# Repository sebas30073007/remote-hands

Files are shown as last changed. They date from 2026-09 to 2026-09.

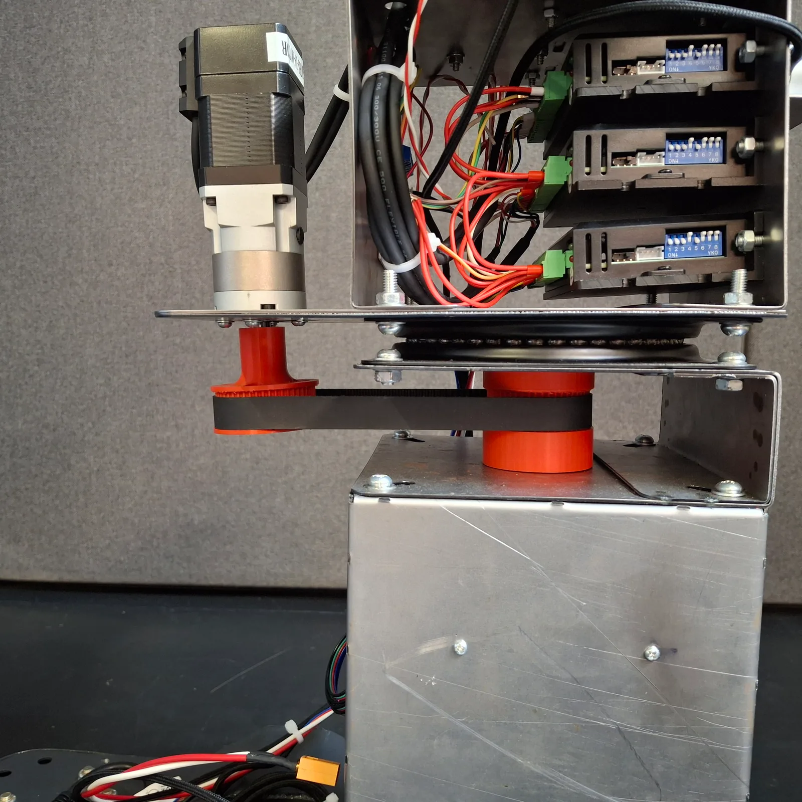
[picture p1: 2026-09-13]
public/images/build/base-rotatoria-lateral.webp

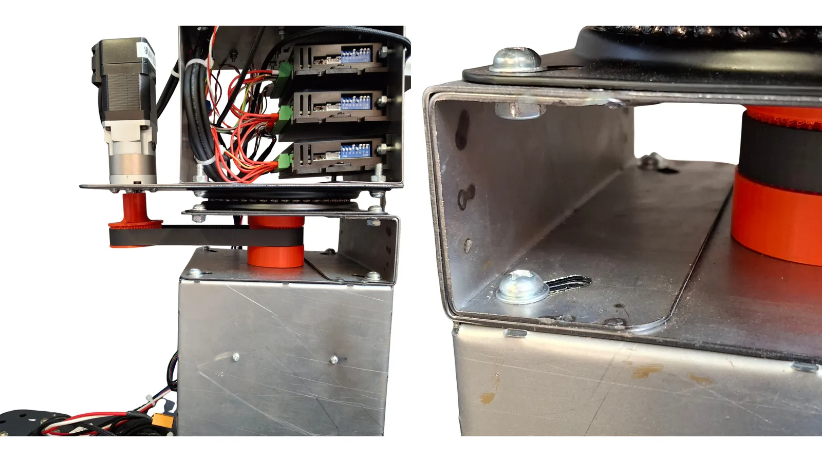
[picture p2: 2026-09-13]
public/images/build/eje-rotacional-base.webp

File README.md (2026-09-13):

# Remote Hands

Documentación de ingeniería de **Remote Hands**: un robot móvil con brazo
manipulador de 3 GDL, teleoperado desde un visor Meta Quest 3.

Un operador controla el robot a distancia con una interfaz de realidad
mixta hecha en Unity. A bordo, una NUC coordina el sistema: procesa la
percepción (RPLiDAR C1 y RealSense D435i), mantiene la comunicación con el
operador por ZeroMQ sobre WiFi y reparte las órdenes entre tres
controladores ESP32-C3 —tracción, manipulador y gripper—.

**Sitio:** [remote-hands.sebs.mx](https://remote-hands.sebs.mx)

Proyecto Terminal universitario. Del experimento de latencia salió un
artículo para el IEEE World Forum on IoT, y el proyecto se postuló al James
Dyson Award 2026.

## Qué hay aquí

Un sitio de documentación construido con [Astro](https://astro.build) y
[Starlight](https://starlight.astro.build). Se escribe en MDX con un
vocabulario de ingeniería propio: requisitos, interfaces, verificación,
decisiones de arquitectura (ADR), niveles de replicación y artefactos
descargables.

Además de la documentación, el repositorio publica lo necesario para
replicar el robot: firmware, código de la NUC, archivos de fabricación de
las PCB, planos DXF del manipulador y el dataset del experimento de latencia.

### Navegación por vista explosionada

El sitio tiene dos formas de navegar, que se alternan con el botón **UI/UX**
de la barra superior:

- **Lista**: el temario clásico.
- **Explosión**: el robot dibujado a partir de su CAD. Al elegir una pieza,
  la página cambia y el dibujo se separa en las piezas de esa parte.

Las imágenes de la explosión no son un modelo 3D embebido: son capas
renderizadas desde el CAD con cámara ortográfica, que el navegador traslada
con CSS.

## Empezar

```bash
npm install
npm run dev       # http://localhost:4321/
npm run build     # genera dist/
npm run check     # tipos y frontmatter
```

## Estructura

```text
src/
├── content/docs/   páginas del sitio (MDX)
├── components/
│   ├── core/       primitivas genéricas
│   └── project/    vocabulario de ingeniería: import { … } from '@project'
├── overrides/      componentes de Starlight sustituidos
├── lib/            configuración del proyecto y árbol de la vista explosionada
├── generated/      manifiesto de la vista explosionada (generado)
└── styles/         identidad SEBS y estilos del sitio
public/
├── models/         modelos 3D optimizados (.glb)
├── explode/        capas renderizadas de la vista explosionada
├── pcb/ firmware/ software/ cad/ datasets/   artefactos descargables
scripts/            pipelines de imágenes y modelos
```

## Pipeline de la vista explosionada

Los modelos originales (Inventor, KiCad) no se versionan: pesan ~50 MB. Si
cambia el CAD, se regeneran así:

```bash
node scripts/optimize-models.mjs   # raw assets/*.glb  ->  public/models/
node scripts/render-explode.mjs    # public/models/    ->  public/explode/ + manifiesto
```

Qué piezas forman cada capa y hacia dónde se separan está en
`scripts/explode-scenes.mjs`; a qué página lleva cada pieza, en
`src/lib/explode-nav.ts`.

## Despliegue

Cada push a `main` compila y publica en GitHub Pages
(`.github/workflows/deploy.yml`). El sitio se sirve en el subdominio
`remote-hands.sebs.mx`, configurado en *Settings → Pages* del repositorio y
con un registro `CNAME` en el DNS de `sebs.mx`.

`site` y `base` están en `astro.config.mjs`. Las rutas internas del
contenido se escriben desde la raíz (`/sistema/…`) y se ajustan al `base` al
compilar, así que mover el sitio a otra ruta solo cambia `BASE`.

## Escribir contenido

El frontmatter `type` (`project`, `subsystem`, `procedure`, `experiment`,
`decision`, `release`, `reference`) coloca la cabecera de la página
automáticamente. Los componentes se importan en una línea:

```mdx
import { ParameterTable, InterfaceTable, Requirement, VerificationResult, Artifact } from '@project';
```

Las páginas de `src/content/docs/sistema/subsistemas/robot-movil/` son la
referencia del patrón.

## Autor

Sebastián Méndez — [sebs.mx](https://sebs.mx)

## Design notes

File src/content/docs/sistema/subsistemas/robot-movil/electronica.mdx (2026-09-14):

---
title: Puente H
description: La placa que mueve los motores DC de tracción — qué es, cómo funciona, cómo se conecta, su PCB y su firmware.
# Tres bloques grandes en el índice de la página: Sinopsis, PCB y Firmware.
tableOfContents:
  minHeadingLevel: 2
  maxHeadingLevel: 2
---

import { ParameterTable, InterfaceTable, Artifact, SignalChain } from '@project';

<figure>
  Módulo Puente H de frente: ESP32-C3, MOSFETs con disipador, capacitor de filtrado y borneras
</figure>

El Puente H es la placa que mueve los motores de tracción del robot. Recibe
una consigna de velocidad y la convierte en la potencia que llega al motor.
El robot lleva dos, uno por motor.

## Sinopsis

### Qué es

Una tarjeta de control de motor DC de **diseño propio**. Usa una topología de
puente H discreto, con aislamiento óptico entre la lógica y la potencia, y un
**ESP32-C3** que gestiona los modos de comunicación.

<ParameterTable
  caption="Características eléctricas"
  rows={[
    { parameter: 'Alimentación de potencia', value: '12–24', unit: 'V DC nominal' },
    { parameter: 'Corriente continua deseada', value: '4–5', unit: 'A' },
    { parameter: 'Corriente pico máxima', value: '8', unit: 'A' },
    { parameter: 'Microcontrolador', value: 'ESP32-C3 SuperMini', unit: '—' },
    { parameter: 'Aislamiento lógica/potencia', value: 'Optoacopladores 4N25', unit: '—' },
    { parameter: 'MOSFETs alto lado', value: 'IRF9540N', unit: 'canal P, 117 mΩ' },
    { parameter: 'MOSFETs bajo lado', value: 'IRF540N', unit: 'canal N, 44 mΩ' },
  ]}
/>

<figure>
  Esquema de bloques funcionales del puente H
  <figcaption>Etapa de potencia, aislamiento óptico, control embebido, expansión I²C y protección.</figcaption>
</figure>

1. **Etapa de potencia** — puente H con MOSFETs IRF540N (N) e IRF9540N (P).
2. **Aislamiento de control** — optoacopladores 4N25 que separan la lógica
   del circuito de conmutación.
3. **Control embebido** — el ESP32-C3 administra modos de comunicación,
   lógica de mando y estados.
4. **Interfaz de expansión** — conectores I²C de entrada y salida para la
   arquitectura maestro-esclavo.
5. **Protección e indicación** — fusible de entrada, capacitor de filtrado,
   LEDs de estado, botón local.

### Cómo funciona

Al encender, la placa lee su DIP switch **una sola vez**, y esa lectura fija
por dónde recibe las órdenes: I²C como maestro o esclavo, WiFi, BLE o
Bluetooth clásico. En el robot, un módulo arranca como maestro y el otro como
esclavo. Por USB-C acepta órdenes siempre, sea cual sea el modo.

#### Modos de operación (DIP switch)

| SW3 | SW2 | SW1 | Modo | Descripción |
| --- | --- | --- | --- | --- |
| 0 | 0 | 0 | Prueba local | Validación interna; rutina activable por botón |
| 0 | 0 | 1 | WiFi | Recibe comandos por red inalámbrica |
| 0 | 1 | 0 | BLE | Bluetooth Low Energy |
| 0 | 1 | 1 | HC-05 | Bluetooth clásico por UART externo |
| 1 | 0 | 0 | I²C Maestro | Nodo maestro en arquitectura distribuida |
| 1 | 0 | 1 | I²C Slave 1 | Esclavo 1 (dirección reservada) |
| 1 | 1 | 0 | I²C Slave 2 | Esclavo 2 (dirección reservada) |
| 1 | 1 | 1 | I²C Slave 3 | Esclavo 3 (dirección reservada) |

La placa arranca con la salida al motor deshabilitada, y solo la habilita
tras una orden explícita de armado. Para mover el motor activa una de las dos
diagonales del puente con PWM: una diagonal gira en un sentido, la otra en el
contrario.

#### Tabla funcional del puente H

`PWM_0 = 1` y `PWM_1 = 1` simultáneamente está **prohibido**: provoca
cortocircuito entre rieles de potencia.

| PWM_0 | PWM_1 | Estado | Descripción |
| --- | --- | --- | --- |
| 0 | 0 | Libre / deshabilitado | Ambos caminos apagados |
| 1 | 0 | Giro A | Activa diagonal A; combinable con PWM |
| 0 | 1 | Giro B | Activa diagonal B; combinable con PWM |
| 1 | 1 | **Prohibido** | Riesgo de cortocircuito |

### Conexiones

De la NUC a las ruedas. El maestro recibe las órdenes por USB y reenvía la
suya al esclavo por I²C; cada módulo mueve su propio motor.

<SignalChain
  porFila={2}
  pasos={[
    { nombre: 'NUC', detalle: 'Python 3.12', imagen: '/images/3d/nuc.webp' },
    { nombre: 'Puente H maestro', detalle: 'ESP32-C3 · DIP 100', imagen: '/images/3d/puente-h.webp' },
    { nombre: 'Puente H esclavo', detalle: 'ESP32-C3 · I²C 0x08', imagen: '/images/3d/puente-h.webp' },
    { nombre: 'Motores DC de tracción', detalle: 'base diferencial · 12–24 V', imagen: '/images/3d/base-diferencial.webp' },
  ]}
  enlaces={['USB-CDC · COM4', 'I²C 0x08 · tramas binarias', 'Salida al motor · uno por módulo']}
/>

<InterfaceTable
  caption="Conectores de la placa"
  columns={['Conector', 'Pines', 'Descripción']}
  rows={[
    ['Entrada de potencia', '2', 'Entrada principal de 12–24 V DC'],
    ['Salida al motor', '2', 'Terminales del puente H hacia la carga'],
    ['Data_in I²C', '4', '+5V, SDA, SCL, GND — recibe el bus desde el maestro'],
    ['Data_out I²C', '4', 'Réplica del bus para encadenar el siguiente módulo'],
    ['Header HC-05', '6', '+5V, GND, RX, TX — Bluetooth clásico o debug UART'],
    ['USB-C (ESP32-C3)', '—', 'Programación, alimentación digital y debug prioritario'],
  ]}
/>

<figure>
  Interior de la caja de elevación con los módulos Puente H montados
  <figcaption>Los dos módulos alojados dentro de la estructura metálica que eleva el manipulador, sobre soportes impresos y sin cajas externas.</figcaption>
</figure>

## PCB

### La placa

Se diseñó en KiCad 9 y se fabricó en JLCPCB. Los valores de abajo están
leídos del archivo de layout, no transcritos: son los que hay que declarar al
pedir la placa.

<ParameterTable
  caption="Especificación de fabricación"
  rows={[
    { parameter: 'Dimensiones', value: '80,6 × 73,4', unit: 'mm' },
    { parameter: 'Capas de cobre', value: '2', unit: 'F.Cu / B.Cu' },
    { parameter: 'Espesor de placa', value: '1,6', unit: 'mm' },
    { parameter: 'Vías', value: '14', unit: '—' },
    { parameter: 'Ancho de pista — potencia', value: '2,0', unit: 'mm', notes: 'Diagonales del puente y rieles de alimentación' },
    { parameter: 'Ancho de pista — señal', value: '0,3 – 1,0', unit: 'mm' },
  ]}
/>

<figure>
  Esquemático del Puente H en KiCad
  <figcaption>ESP32-C3, optoacopladores 4N25, MOSFETs IRF540N/IRF9540N, conectores de potencia e I²C.</figcaption>
</figure>

<figure>
  Layout PCB de dos capas del Puente H
  <figcaption>El ruteo separa los planos de potencia —pistas de 2,0 mm— de las señales lógicas del microcontrolador.</figcaption>
</figure>

Para pedir la placa basta subir `gerbers.zip` tal cual al fabricante y dejar
los parámetros por defecto de dos capas: el espesor de 1,6 mm y el acabado
estándar son los que se usaron. El ZIP incluye los taladros PTH, así que no
hay que exportar nada aparte.

#### Costo de fabricación

Cifras reales de JLCPCB para un lote de 10 piezas de dos capas, sin ensamble
de fábrica. El Controlador CL57T cae en el mismo rango.

| Concepto | Costo aproximado |
| --- | --- |
| Producción | 5,00 USD |
| Envío | 17,50 USD |
| Derechos de importación | 130 MXN |

El envío pesa más del triple que la producción. Por eso conviene pedir el
Puente H y el Controlador CL57T en el mismo lote, y pedir diez piezas cuando
hacen falta dos.

<Artifact href="/pcb/puente-h/gerbers.zip" name="Gerbers de fabricación — Puente H" />
<Artifact href="/pcb/puente-h/kicad-proyecto.zip" name="Proyecto KiCad completo — Puente H" />
<Artifact href="/datasheets/datasheet_puente_h_esp32c3.pdf" name="Datasheet Puente H ESP32-C3" />

#### Lista de materiales

54 componentes en 21 referencias distintas, ordenados por función: el orden
que importa al replicar es el de la compra.

<InterfaceTable
  caption="Lista de materiales — módulo Puente H"
  columns={['Designadores', 'Cant.', 'Valor', 'Encapsulado']}
  rows={[
    ['U1', 1, 'ESP32-C3 SuperMini', 'Módulo SMD'],
    ['Q1, Q2', 2, 'IRF9540N (canal P)', 'TO-220-3 vertical'],
    ['Q3, Q4', 2, 'IRF540N (canal N)', 'TO-220-3 vertical'],
    ['U2–U5', 4, '4N25', 'DIP-6, paso 7,62 mm'],
    ['D4–D7', 4, '1N47xxA (Zener — ver nota)', 'DO-41 horizontal'],
    ['D1', 1, 'LED indicador', '1206'],
    ['D2', 1, 'LED de datos', '1206'],
    ['D3', 1, 'LED de potencia', '1206'],
    ['C1, C3, C4', 3, '100 nF', '1206'],
    ['C2', 1, '2200 µF 50 V', 'Radial D16 mm, paso 7,5 mm'],
    ['R1–R4, R14, R15', 6, '330 Ω', '1206'],
    ['R7, R8, R10, R11, R16–R19', 8, '10 kΩ', '1206'],
    ['R6, R9, R12, R13', 4, '2,2 kΩ', '1206'],
    ['R20, R21', 2, '4,7 kΩ', '1206'],
    ['R5', 1, '3,3 kΩ', '1206'],
    ['F1', 1, 'Portafusible 5 × 20 mm', 'Clip inline horizontal'],
    ['SW3', 1, 'DIP switch 4 posiciones', 'Slide, paso 2,54 mm'],
    ['SW2', 1, 'Pulsador', 'RS-032G05A3-SMRT'],
    ['M1', 1, 'Bornera salida a motor', 'MX126-5.0, 2 P'],
    ['VP_IN1, VP_OUT1', 2, 'Bornera de potencia', 'MX126-5.0, 2 P'],
    ['DATA_IN1, DATA_OUT1', 2, 'Conector I²C', 'JST EH 4 P vertical'],
    ['CONN01X06', 1, 'Header HC-05', 'JST EH 6 P vertical'],
    ['J1–J4', 4, 'Puente de alambre', '0,5 mm²'],
  ]}
/>

Dos advertencias antes de comprar:

- **Los Zener D4–D7 no tienen valor cerrado.** El esquemático usa el símbolo
  genérico `1N47xxA` de la librería de KiCad, cuyo datasheet por defecto
  apunta al **1N4728A** (3,3 V, 1 W). Ese enlace viene de la librería, no de
  una elección registrada en el diseño, así que hay que confirmar la tensión
  contra la placa física antes de pedir.
- **La columna `LCSC Part #` del BOM está vacía.** No hay números de parte de
  proveedor, así que la compra se resuelve por valor y encapsulado.

<Artifact href="/pcb/puente-h/bom.csv" name="Lista de materiales — Puente H (CSV)" />
<Artifact href="/pcb/puente-h/positions.csv" name="Posiciones para ensamble — Puente H (CSV)" />

#### Ensamble

La placa mezcla SMD 1206 con componentes de orificio pasante voluminosos
—MOSFETs TO-220, capacitor radial de 16 mm, borneras—, así que el ensamble
manual es viable y fue el que se usó. El orden va de menor a mayor altura,
para que un componente alto no estorbe el acceso a uno bajo:

1. Resistencias y capacitores 1206, y los LED.
2. Optoacopladores 4N25 en sus zócalos DIP-6. Respeta la marca de pin 1.
3. Zener D4–D7 y los puentes J1–J4.
4. Módulo ESP32-C3 SuperMini.
5. DIP switch y pulsador.
6. MOSFETs TO-220 — los cuatro van verticales.
7. Portafusible, borneras, conectores JST y el capacitor de 2200 µF.

Antes de aplicar potencia por primera vez conviene verificar continuidad
entre los rieles de alimentación y masa: un corto ahí es el fallo que la
topología de puente H castiga más rápido.

<figure>
  Detalle de la PCB del Puente H con ESP32-C3, DIP switch y conectores I²C
  <figcaption>ESP32-C3 SuperMini, conector I²C etiquetado (5 V, SDA, SCL, GND), borneras y DIP switch de selección de modo.</figcaption>
</figure>

### Asignación de pines

| Señal | GPIO | Función |
| --- | --- | --- |
| `PWM_0` | GPIO6 | Salida de mando — diagonal A del puente H |
| `PWM_1` | GPIO7 | Salida de mando — diagonal B del puente H |
| `SDA` | GPIO8 | Datos del bus I²C |
| `SCL` | GPIO9 | Reloj del bus I²C |
| `LED` | GPIO10 | LED de usuario / depuración |
| `RX` / `TX` | GPIO20 / GPIO21 | UART para módulo HC-05 |
| `S0`, `S1`, `S2` | GPIO1, GPIO3, GPIO4 | Lectura del DIP switch |
| `BTN` | GPIO5 | Botón local (pull-up interno) |

## Firmware

MicroPython sobre el ESP32-C3. Acepta comandos por USB-C —canal prioritario,
siempre activo— o por el medio seleccionado con el DIP switch.

<Artifact href="/firmware/main_movil_final.py" name="Firmware — main_movil_final.py" />

Para cargarlo: instala el intérprete de MicroPython para ESP32-C3 en el
módulo, copia el archivo como `main.py` en su sistema de archivos y
reinicia. El firmware arranca leyendo el DIP switch, así que hay que fijar el
modo **antes** de alimentar la placa.

### Máquina de estados

```text
  BOOT
   │  lee DIP switch (solo una vez)
   ▼
DISARMED ──── ARM explícito o botón largo ────► ARMED
   ▲                                              │
   └─── timeout 2 500 ms sin comando ────────────┘
   │
FAULT ◄─── cortocircuito / error de checksum
```

La salida al motor permanece deshabilitada en `DISARMED`. Pasar a `ARMED`
exige un comando explícito, así que el robot no puede moverse por accidente
al encenderse ni al reconectarse.

### Protocolo I²C binario

En los modos maestro y esclavo, todos los comandos al Puente H viajan como
paquetes binarios de 7 bytes. El maestro construye la trama; los esclavos la
validan antes de ejecutar.

| Byte | Campo | Descripción |
| --- | --- | --- |
| 0 | `PREAMBLE` | Siempre `0xA5` — marca de sincronía |
| 1 | `SEQ` | Número de secuencia 0–255 para detección de duplicados |
| 2 | `CMD_MODE` | `0` STOP, `1` TARGET, `2` TEST |
| 3–4 | `LO`, `HI` | Consigna con signo como `int16` little-endian |
| 5 | `FLAGS` | Bitmask: `ARMED (0x01)`, `FAULT (0x02)`, `TEST (0x04)` |
| 6 | `CHECKSUM` | XOR de los bytes 0–5 |

Si el checksum no coincide, el paquete se descarta silenciosamente y el
motor permanece en su último estado: nunca se ejecuta un movimiento con
datos corruptos.

### Deadtime y rampas

Conmutar ambas diagonales del puente H a la vez provoca cortocircuito. Para
evitarlo, `apply_bridge_local_safe()` impone **300 µs** de tiempo muerto
entre cambios de diagonal.

Ningún cambio de velocidad es instantáneo. El duty cycle sube o baja 1 %
cada 20 ms hasta alcanzar la consigna, con un techo de 70 %. Pasar de 0 % a
velocidad máxima toma por tanto 1,4 s como mínimo, y esa rampa es la que
limita las corrientes de arranque y el estrés mecánico sobre los motores DC.

El techo del 70 % es una decisión de seguridad de la [plataforma
móvil](/sistema/subsistemas/robot-movil/plataforma-movil/#cómo-funciona): con
el manipulador montado, acelerar a fondo compromete la estabilidad.

<ParameterTable
  caption="Parámetros de tracción, leídos del firmware"
  rows={[
    { parameter: 'Frecuencia PWM', value: '1000', unit: 'Hz' },
    { parameter: 'Tiempo muerto entre diagonales', value: '300', unit: 'µs', notes: 'Evita el cortocircuito de puente' },
    { parameter: 'Techo de velocidad', value: '70', unit: '% de duty' },
    { parameter: 'Rampa', value: '1 % cada 20', unit: 'ms', notes: '1,4 s de 0 % al techo' },
    { parameter: 'Timeout de comunicación', value: '2500', unit: 'ms', notes: 'Sin comando, vuelve a DISARMED' },
    { parameter: 'Refresco maestro → esclavo', value: '80', unit: 'ms' },
    { parameter: 'Baudios del enlace serie', value: '115200', unit: 'bps' },
    { parameter: 'Prioridad de USB', value: '8000', unit: 'ms', notes: 'Ventana en que USB desplaza al medio del DIP switch' },
  ]}
/>

### Prueba desde tu PC

El maestro acepta por USB los mismos comandos de texto que le manda la NUC,
así que se prueba conectándolo directo a una PC. El script consulta la placa
y el bus I²C y, si se lo pides, mueve los dos motores unos segundos,
reenviando la orden a 15 Hz como la NUC para que no salte el timeout de
2,5 s.

1. Pon el DIP switch en `100` (maestro) **antes** de alimentar la placa.
2. Conecta el USB-C del ESP32-C3 a la PC. Para mover, conecta también la
   potencia y deja las ruedas en el aire.
3. Instala la dependencia: `pip install pyserial`.
4. Corre la prueba:

```bash
python prueba_puente_h.py --puerto COM4
python prueba_puente_h.py --puerto COM4 --mover --consigna 80 --segundos 3
python prueba_puente_h.py --puerto COM4 --consola
```

<Artifact href="/software/pruebas/prueba_puente_h.py" name="Prueba del Puente H — prueba_puente_h.py" />

La placa debe responder `PONG`, su estado, y `I2C_SCAN:0x8,0xb` si el
esclavo y el controlador CL57T están conectados al bus. Con `--consola`
puedes escribir cualquier comando; `HELP` los lista.

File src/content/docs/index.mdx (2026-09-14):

---
title: Remote Hands
# La pestaña mostraba «Remote Hands | Remote Hands»: Starlight compone
# «título de página | título del sitio», y en la portada son el mismo.
head:
  - tag: title
    content: Remote Hands — Documentación de ingeniería
description: Plataforma de teleoperación para manipulación móvil — robot móvil con brazo manipulador de 3 GDL, servidor de percepción y control por interfaz XR en Meta Quest.
type: project
status: prototype
currentRelease: "sin versionar aún"
projectType:
  - Robótica
  - XR
  - Proyecto Terminal
---

import { StatusBadge, SignalChain } from '@project';

Remote Hands es un robot móvil con un brazo manipulador de tres grados de
libertad, construido desde cero. Un operador lo controla a distancia desde
un headset **Meta Quest**, con una interfaz hecha en Unity.

A bordo, una NUC coordina el sistema completo. Procesa la percepción —LiDAR
y cámara RGB-D—, mantiene la comunicación con el operador por **ZeroMQ sobre
WiFi**, y traduce sus comandos en instrucciones para tres controladores
embebidos. Cada controlador resuelve el movimiento de bajo nivel de su
propio subsistema.

## El sistema

Tres partes y los dos enlaces que las unen. Cada tarjeta lleva a su
documentación.

<SignalChain
  pasos={[
    {
      nombre: 'Meta Quest 3',
      detalle: 'operador · Unity',
      imagen: '/images/3d/meta-quest-3.webp',
      href: '/sistema/subsistemas/interfaz-xr/',
    },
    {
      nombre: 'NUC',
      detalle: 'coordinador a bordo',
      imagen: '/images/3d/nuc.webp',
      href: '/sistema/subsistemas/servidor-percepcion/',
    },
    {
      nombre: 'Robot',
      detalle: 'plataforma y brazo de 3 GDL',
      imagen: '/images/3d/robot.webp',
      href: '/sistema/subsistemas/robot-movil/',
    },
  ]}
  enlaces={[
    { medio: 'ZMQ por WiFi', ida: 'comandos', vuelta: 'video · LiDAR · estado' },
    { medio: 'USB · I²C', ida: 'consignas', vuelta: 'telemetría' },
  ]}
/>

La NUC es el coordinador único: recibe comandos simples por ZMQ y los
reparte entre tres controladores embebidos independientes —tracción,
manipulador y gripper—, cada uno con su propio protocolo. El porqué de esa
división está registrado en
[ADR-0001](/registro/#adr-0001-la-nuc-como-coordinador-único), y
el detalle completo en [Arquitectura del
sistema](/sistema/arquitectura/resumen/).

### Estado de cada subsistema

| Subsistema | Estado |
| --- | --- |
| [Robot](/sistema/subsistemas/robot-movil/) | Construido y probado |
| [Servidor / NUC](/sistema/subsistemas/servidor-percepcion/) | Verificado — watchdog parcial |
| [Visor Meta Quest](/sistema/subsistemas/interfaz-xr/) | Verificado |

La integración de los tres en un lazo de control extremo a extremo sigue en
proceso. Cada subsistema publica su propio estado detallado en su página de
verificación.

## Archivos clave

- **Firmware** de los tres controladores ESP32-C3 (MicroPython) y del stack
  de coordinación de la NUC (Python 3.12 + ZMQ).
- **PCB propias**: módulo Puente H (tracción) y controlador CL57T
  (manipulador), diseñadas en KiCad con Gerbers de fabricación.
- **CAD del manipulador** (Autodesk Inventor): ensamble completo y piezas de
  corte láser en DXF.
- **Dataset de latencia** WiFi, con 7 350 muestras sobre siete condiciones de
  carga: ver
  [experimento de latencia](/latencia-wifi/#resultados).

## Estado del proyecto

<StatusBadge label="Prototipo" tone="info" /> El robot está construido y sus
tres subsistemas están validados por separado. Falta cerrar la integración
de control extremo a extremo, de la Meta Quest a la electrónica embebida.

La migración de contenido desde la documentación previa del proyecto
—Jekyll con Just the Docs— sigue en curso. Las secciones del temario sin
contenido real no se rellenaron con texto inventado: cada una lleva una
página que declara qué falta y por qué.

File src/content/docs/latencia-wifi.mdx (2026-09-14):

---
title: Experimento de latencia WiFi
description: "El experimento de latencia entre el visor y la NUC: protocolo, método para repetirlo y análisis de 7 350 sondeos."
tableOfContents:
  minHeadingLevel: 2
  maxHeadingLevel: 2
---

import { VerificationResult, Artifact } from '@project';

El único experimento con datos del proyecto: cuánto tarda un mensaje en ir del visor a la NUC y volver, bajo siete condiciones de carga de red. Primero el protocolo, luego cómo repetirlo y al final los resultados.

## Protocolo

> **Hipótesis (EXP-LAT-001).** La latencia de protocolo (RTT) entre la interfaz XR y la NUC se mantiene utilizable (P95 < 100 ms) incluso bajo carga combinada de video y LiDAR de alta resolución.

El protocolo del experimento de latencia: qué se mide exactamente, con qué instrumentos, bajo qué condiciones de carga y con qué criterio de aceptación. Se escribe antes de los resultados a propósito — es lo que permite que otro lo repita y compare.

### Objetivo

Medir la **latencia de ida y vuelta (RTT) a nivel de aplicación** entre la
interfaz de realidad mixta y un nodo edge simulado en PC.

El enlace bajo prueba es ZeroMQ sobre red WiFi local. La medición se repite
bajo distintas condiciones de carga, para observar cómo afecta el tráfico
concurrente a la latencia de los comandos.

### Alcance y limitaciones

**Esta prueba mide:**
- Latencia de protocolo MR-edge: tiempo desde que Unity envía
  `latency_probe` hasta que recibe `latency_ack`.
- Impacto de cargas concurrentes (video JPEG 640×480, LiDAR 2D grid JSON)
  sobre la latencia de comandos.

**Esta prueba NO mide:**
- Latencia física del robot (serial, ESP32, drivers, motores, respuesta
  mecánica).
- Latencia de actuación total del sistema teleoperado.
- Latencia de ida vs. vuelta por separado — requeriría sincronización de
  relojes NTP/PTP entre dispositivos.

**Definición de RTT:**

```text
RTT = client_receive_ts − client_send_ts   (Time.unscaledTime de Unity)
```

La medición no asume ninguna sincronización de reloj entre la Quest y la PC.
Los campos `server_recv_unix` y `server_send_unix` que viajan en el ACK son
informativos; el cálculo del RTT no los usa.

### Condiciones experimentales

Siete condiciones, cada una variando la carga de video y LiDAR presente
durante la medición de latencia de comandos:

| ID | Nombre | Video | LiDAR | Modo cámara | Modo LiDAR | LiDAR Hz |
| --- | --- | --- | --- | --- | --- | --- |
| C1 | `C1_control_only` | No | No | off | off | — |
| C2 | `C2_video_normal` | Sí | No | normal | off | — |
| C3 | `C3_lidar_detail` | No | Sí | off | detail | 12 |
| C4 | `C4_lidar_medium` | No | Sí | off | medium | 8 |
| C5 | `C5_lidar_panorama` | No | Sí | off | panorama | 4 |
| C6 | `C6_full_detail` | Sí | Sí | normal | detail | 12 |
| C7 | `C7_full_panorama` | Sí | Sí | normal | panorama | 4 |

### Parámetros de la prueba

| Parámetro | Valor |
| --- | --- |
| Duración por condición | 60 s |
| Tasa de sondeo (probe rate) | 10 Hz (≈ 600 muestras por condición) |
| Repeticiones | 3 por condición, cuando el tiempo lo permite |
| Warm-up descartado | Primeras 10 muestras |
| Red WiFi | 5 GHz, distancia &lt; 5 m sin obstáculos |
| Escenario | Mismo cuarto, sin otros dispositivos en la red si es posible |

### Texto de limitaciones para el paper

El párrafo siguiente está redactado para citarse tal cual en una
publicación. Conserva a propósito la densidad de la prosa académica, así que
no sigue las mismas reglas de redacción que el resto de este sitio.

> La prueba mide latencia de protocolo de la capa de aplicación MR-edge (RTT
> entre Unity/Quest y el nodo edge simulado), usando ZeroMQ sobre IEEE
> 802.11ac (WiFi 5 GHz). El RTT incluye serialización JSON, latencia de red
> WiFi (ida y vuelta) y deserialización, pero **no incluye** latencia
> serial, control de motores ni respuesta mecánica del robot. El RTT no
> puede separarse en latencia de ida y vuelta sin sincronización de relojes
> (NTP/PTP) entre los dispositivos; se reporta como RTT observado desde la
> perspectiva del operador en el visor MR. La carga de video y LiDAR es
> sintética pero usa los mismos canales ZMQ, frecuencias y tamaños de
> payload aproximados del sistema real.

## Método

Reproducir el experimento requiere dos máquinas: una PC que ejecuta el
simulador del nodo edge, y una Meta Quest con la aplicación de prueba
instalada. Esta sección cubre el montaje, la ejecución y la extracción de los
datos. El diseño experimental está en el
[protocolo](/latencia-wifi/#protocolo).

### Requisitos

| Componente | Requisito |
| --- | --- |
| PC (simulador) | Windows / Linux / macOS, Python 3.10+ |
| Python | `pyzmq ≥ 25`, `opencv-python ≥ 4.8`, `numpy ≥ 1.24` |
| Red | PC y Quest en la misma red WiFi (preferible 5 GHz) |
| Quest | Meta Quest 3, APK con `WFIoTLatencyTestScene` |
| Unity | Scripts copiados desde `validation/Assets/Scripts/WFIoTLatency/` |

### Simulador Python

```bash
cd <repo>/validation/tools
python wfiot_nuc_latency_simulator.py --host 0.0.0.0 --video-fps 30 --stat-hz 2 --lidar-hz 12 --jpeg-quality 85
```

Para las condiciones de LiDAR panorama (C5 y C7), con payload reducido:

```bash
python wfiot_nuc_latency_simulator.py --lidar-hz 4 --compact-lidar
```

Al arrancar, el simulador imprime su propia IP y los puertos que deja
activos. Para averiguar la IP abre un socket UDP hacia 8.8.8.8, sin llegar a
enviar datos. El significado de cada puerto está en [Comunicaciones del
sistema](/sistema/arquitectura/comunicaciones/#puertos-zmq-verificados).

### Ejecución en la Quest

Por cada condición del experimento:

1. Selecciona el preset de condición (C1 a C7) en el dropdown de la
   aplicación.
2. Confirma que los toggles de video y LiDAR coinciden con lo que el preset
   declara.
3. Pulsa **Start**. La corrida dura 60 s a 10 Hz.

Al terminar, la aplicación exporta dos CSV automáticamente:

```text
/sdcard/Android/data/<bundle_id>/files/
  wfiot_latency_results_YYYYMMDD_HHMMSS.csv   ← detalle por muestra
  wfiot_latency_summary_YYYYMMDD_HHMMSS.csv   ← resumen estadístico
```

Para extraerlos por ADB:

```bash
adb pull /sdcard/Android/data/<bundle_id>/files/ ./csv_export/
```

### Columnas relevantes

| CSV | Columna | Descripción |
| --- | --- | --- |
| detalle | `rtt_ms` | RTT observado en milisegundos |
| detalle | `warmup` | `true` = descartar del análisis estadístico |
| resumen | `rtt_p95_ms` | Percentil 95 — 95 % de las muestras tuvieron RTT ≤ este valor |
| resumen | `jitter_std_ms` | Desviación estándar de la latencia |
| resumen | `loss_percent` | Porcentaje de sondeos sin ACK recibido |

### Análisis estadístico

El script `validation/tools/wfiot_stats_analysis.py` procesa los CSV crudos y
produce seis análisis:

- Kruskal-Wallis, como prueba ómnibus entre condiciones.
- Comparaciones pareadas de Mann-Whitney, con corrección de Holm.
- Intervalos de confianza por bootstrap.
- Probabilidad de cola.
- Clústeres de ráfagas.
- Modelo de carga ofrecida.

Los números que arroja sobre los datos reales están en
[Resultados](/latencia-wifi/#resultados).

## Resultados

El experimento reunió **7 350 sondeos medidos** sobre siete condiciones de
carga, con las muestras de warm-up ya excluidas.

<figure>
  Diagrama de caja del RTT medido por condición de carga
  <figcaption>RTT por condición de carga. La caja muestra el rango intercuartílico; los bigotes, la dispersión que importa para el P95.</figcaption>
</figure>

Todas las cifras de esta sección proceden de
`IEEE_IOT/analysis/stats_report.md` del proyecto original, que
`wfiot_stats_analysis.py` generó a partir de los CSV crudos exportados desde
la Meta Quest.

<Artifact href="/datasets/stats_summary.csv" name="stats_summary.csv" contents="Resumen estadístico por condición: media, mediana, P95, P99, jitter" />
<Artifact href="/datasets/stats_report.md" name="stats_report.md" contents="Reporte completo del análisis estadístico" />

### Estadística descriptiva por condición

| Condición | n | Media (ms) | Mediana (ms) | Mín (ms) | Máx (ms) | P95 (ms) | P99 (ms) | Jitter σ (ms) |
| --- | ---: | ---: | ---: | ---: | ---: | ---: | ---: | ---: |
| C1 · control solo | 1050 | 22,54 | 16,62 | 3,44 | 303,57 | 58,10 | 117,43 | 23,38 |
| C2 · video normal | 1050 | 20,20 | 15,87 | 3,63 | 111,47 | 55,26 | 76,84 | 15,24 |
| C3 · LiDAR detail | 1050 | 19,63 | 15,65 | 3,62 | 121,90 | 55,45 | 86,74 | 15,91 |
| C4 · LiDAR medium | 1050 | 22,68 | 17,30 | 3,31 | 156,37 | 63,60 | 93,49 | 19,00 |
| C5 · LiDAR panorama | 1050 | 24,51 | 17,86 | 3,89 | 117,50 | 65,53 | 82,84 | 18,98 |
| C6 · full detail | 1050 | 20,34 | 16,13 | 3,93 | 130,75 | 55,32 | 71,45 | 15,01 |
| C7 · full panorama | 1050 | 25,08 | 17,60 | 3,56 | 118,67 | 71,87 | 83,86 | 19,79 |

<figure>
  Percentiles de RTT por condición de carga
  <figcaption>Percentiles de RTT por condición. El P95 se mantiene por debajo del criterio de 100 ms en las siete condiciones.</figcaption>
</figure>

<VerificationResult
  id="VER-LAT-001"
  requirement="REQ-COM-002"
  method="measurement"
  result="P95 máximo 71,87 ms (C7), P99 máximo 117,43 ms (C1)"
  status="pass"
  evidence={[
    { href: '/datasets/stats_summary.csv', label: 'stats_summary.csv' },
    { href: '/datasets/stats_report.md', label: 'stats_report.md' },
  ]}
/>

El P95 se mantiene por debajo de 100 ms en las siete condiciones probadas.
Eso incluye la carga combinada más pesada, C7, que suma video y LiDAR
panorama con unos 37 Mbps de carga ofrecida.

El resultado contraintuitivo está en la cola de la distribución. La
condición con la cola más larga no es ninguna de las cargadas, sino **C1, la
de solo comandos**: acumula un P99 de 117,43 ms y el RTT máximo de todo el
experimento, 303,57 ms. Esa asimetría apunta a que la cola no la produce el
tráfico de video ni el de LiDAR, sino variabilidad de la red independiente
de la carga aplicada. Los clústeres de ráfagas, más abajo, refuerzan esa
lectura.

### Significancia estadística

La prueba ómnibus de **Kruskal-Wallis** sobre RTT por condición da
H = 70,26 con p &lt; 0,001, para k = 7 y n = 7350. Las siete condiciones no
son, por tanto, estadísticamente idénticas.

Cada condición se compara después contra C1 con la prueba U de
Mann-Whitney, con corrección de Holm por comparaciones múltiples. La delta
de Cliff acompaña a cada p para dar el tamaño del efecto:

| Condición | p (Holm) | Delta de Cliff | Lectura |
| --- | ---: | ---: | --- |
| C2 · video normal | 0,077 | −0,056 | Sin diferencia significativa |
| C3 · LiDAR detail | 0,003 | −0,087 | Significativamente **menor** que C1 |
| C4 · LiDAR medium | 0,614 | 0,013 | Sin diferencia significativa |
| C5 · LiDAR panorama | 0,015 | 0,074 | Significativamente **mayor** que C1 |
| C6 · full detail | 0,151 | −0,045 | Sin diferencia significativa |
| C7 · full panorama | 0,015 | 0,075 | Significativamente **mayor** que C1 |

Las deltas de Cliff son pequeñas en todos los casos: |δ| &lt; 0,1. Con 1 050
muestras por condición, el tamaño de muestra basta para detectar diferencias
estadísticamente, pero su magnitud práctica es modesta.

### Probabilidad de cola — P(RTT &gt; 100 ms)

| Condición | n | n sobre 100 ms | % sobre 100 ms |
| --- | ---: | ---: | ---: |
| C1 · control solo | 1050 | 14 | 1,333 % |
| C2 · video normal | 1050 | 2 | 0,190 % |
| C3 · LiDAR detail | 1050 | 4 | 0,381 % |
| C4 · LiDAR medium | 1050 | 9 | 0,857 % |
| C5 · LiDAR panorama | 1050 | 5 | 0,476 % |
| C6 · full detail | 1050 | 1 | 0,095 % |
| C7 · full panorama | 1050 | 1 | 0,095 % |

<figure>
  Probabilidad de cola del RTT frente a la carga ofrecida
  <figcaption>Probabilidad de cola frente a carga ofrecida. La relación no es monótona: la condición más liviana no es la de menor cola.</figcaption>
</figure>

### Clústeres de ráfagas

Un sondeo por encima de 100 ms no dice mucho por sí solo. Lo relevante es si
esos sondeos aparecen dispersos o agrupados. Aquí se agrupan en un mismo
clúster los eventos separados por menos de 5 s.

<figure>
  Serie temporal de los eventos de latencia alta en la condición C1
  <figcaption>Los eventos de C1 en el tiempo. Se ve por qué 13 de los 14 caen en un solo clúster de 2,82 s en vez de repartirse por la corrida.</figcaption>
</figure>

| Condición | Eventos &gt; 100 ms | Clústeres | Mayor clúster | Duración | RTT máx. (ms) |
| --- | ---: | ---: | ---: | ---: | ---: |
| C1 · control solo | 14 | 2 | 13 | 2,82 s | 303,57 |
| C2 · video normal | 2 | 1 | 2 | 3,11 s | 111,47 |
| C3 · LiDAR detail | 4 | 1 | 4 | 1,01 s | 121,90 |
| C4 · LiDAR medium | 9 | 2 | 8 | 2,82 s | 156,37 |
| C5 · LiDAR panorama | 5 | 2 | 3 | 5,53 s | 117,50 |
| C6 · full detail | 1 | 1 | 1 | 0,00 s | 130,75 |
| C7 · full panorama | 1 | 1 | 1 | 0,00 s | 118,67 |

C1 concentra 13 de sus 14 eventos en un solo clúster de 2,82 s. La cola de
esa condición no es degradación sostenida: es un episodio puntual de red
dentro de una corrida por lo demás limpia. Eso explica por qué la condición
más liviana registra el peor máximo de todo el experimento.

### Modelo de carga ofrecida

El tráfico sintético que compite con los sondeos tiene estos tamaños:

| Fuente | Payload |
| --- | --- |
| Video JPEG (640×480, calidad 85) | 9 756 bytes por frame, de media |
| LiDAR `detail` | 120 122 bytes |
| LiDAR `medium` | 480 122 bytes |
| LiDAR `panorama` | 1 080 124 bytes |

| Condición | Carga ofrecida (Mbps) | Mediana (ms) | P95 (ms) |
| --- | ---: | ---: | ---: |
| C1 | 0,000 | 16,62 | 58,10 |
| C2 | 2,342 | 15,87 | 55,26 |
| C3 | 11,532 | 15,65 | 55,45 |
| C4 | 30,728 | 17,30 | 63,60 |
| C5 | 34,564 | 17,86 | 65,53 |
| C6 | 13,873 | 16,13 | 55,32 |
| C7 | 36,905 | 17,60 | 71,87 |

La correlación de Spearman entre carga ofrecida y P95 es **ρ = 0,750 con
p = 0,052**, sobre las siete condiciones. Es una tendencia positiva que roza
el umbral convencional de significancia, sin cruzarlo. La lectura razonable
es que la cola de latencia sí crece con la carga, pero siete condiciones no
bastan para afirmarlo con significancia estadística formal.

### Conclusión

La hipótesis del experimento **se sostiene** con los datos medidos. El P95
se mantiene por debajo de 100 ms incluso bajo carga combinada: el valor más
alto observado es 71,87 ms, en C7, un 28 % por debajo del umbral.

Los peores casos individuales no aparecen donde cabría esperarlos. Tanto el
P99 más alto como el RTT máximo se registran en C1, la condición más
liviana, y se concentran en un único episodio de 2,82 s. Lo que domina la
cola es la variabilidad de la red, no la carga de datos del robot.

Esa segunda lectura es una interpretación de los datos hecha al migrar la
documentación. Falta que el autor la revise antes de darla por buena para
publicación.

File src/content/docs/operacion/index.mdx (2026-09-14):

---
title: Operación
description: "Cómo encender y operar el robot con seguridad, y qué revisar cuando algo falla."
tableOfContents:
  minHeadingLevel: 2
  maxHeadingLevel: 2
---

import { ParameterTable } from '@project';

Lo que necesita quien opera el robot: cómo llevarlo de apagado a operativo, qué riesgos tiene y qué revisar primero cuando algo falla.

## Puesta en marcha

**Duración:** ~5 min

Llevar el robot de apagado a operativo toma unos **5 minutos**. Casi todo
ese tiempo es el arranque de la NUC; los pasos manuales son pocos.

### Alimentación

El sistema usa tres baterías LiPo independientes, una por subsistema de
potencia:

<ParameterTable
  caption="Baterías"
  rows={[
    { parameter: 'LiPo 6S', value: '6', unit: 'celdas', notes: 'Puentes H — alimenta los MOSFETs de tracción' },
    { parameter: 'LiPo 3S — NUC', value: '3', unit: 'celdas', notes: 'NUC y motor del gripper (12 V, en paralelo)' },
    { parameter: 'LiPo 3S — manipulador', value: '3', unit: 'celdas', notes: 'Drivers CL57T' },
  ]}
/>

Conecta las tres antes de encender la NUC. Así todos los módulos embebidos y
los drivers quedan energizados desde el inicio.

### Secuencia de arranque

1. **Conecta las tres baterías**, en cualquier orden. Los módulos ESP32-C3
   arrancan solos, en estado `DISARMED`, y se quedan esperando comandos.

2. **Enciende la NUC.** Ejecuta sola el script principal de Python 3.12, sin
   que haga falta intervenir. Ese script levanta el middleware ZMQ,
   inicializa el streaming de video y de LiDAR, y abre las conexiones
   seriales con los módulos embebidos por COM4 y COM5.

3. **Averigua la IP de la NUC.** La red del laboratorio no asigna IPs fijas,
   así que cambia en cada arranque. Desde una PC en la misma red:

   ```bash
   arp -a
   ```

   Si conoces el hostname de la NUC, también sirve:

   ```bash
   ping <hostname-de-la-NUC>
   ```

   La vía más directa es conectar un monitor externo a la NUC y leer la IP
   en su terminal.

4. **Escribe esa IP en la aplicación de la Meta Quest.** El campo de IP del
   servidor debe apuntar a la dirección del paso anterior. Este es el único
   punto de fricción del arranque: con una IP fija, el paso desaparecería.

5. **Comprueba que el sistema responde.** Deberías tener video en vivo,
   telemetría y control de movimiento disponibles desde la interfaz XR.

**Antes de armar cualquier controlador**, verifica que el área de trabajo
del robot esté despejada. Los módulos arrancan en `DISARMED` por diseño,
pero el paso a `ARMED` surte efecto de inmediato en cuanto se envía el
comando.

## Seguridad

Remote Hands mueve masa real bajo control remoto, y el operador trabaja con
el campo visual cubierto. Esta sección reúne los riesgos identificados y las
precauciones que el proyecto aplica hoy.

<figure>
  Finales de carrera instalados en la articulación superior y en la base del manipulador
  <figcaption>Los finales de carrera son la primera capa de seguridad del manipulador: acotan el recorrido antes de que lo haga el firmware.</figcaption>
</figure>

### Riesgos identificados

| Riesgo | Origen |
| --- | --- |
| Eléctrico | Alimentación de 12–24 V DC y electrónica de potencia |
| Mecánico | Movimiento de la base móvil y del manipulador |
| De operación remota | El operador no confirma físicamente el estado del entorno |
| De campo visual | El headset Meta Quest limita la visión periférica |

### Precauciones mínimas

- Opera en un área despejada y delimitada.
- Mantén supervisión presencial durante todas las pruebas.
- Verifica el método de detención inmediata antes de cada sesión. La parada
  de emergencia vive en el panel izquierdo de la interfaz (ver [Interfaz y
  controles](/sistema/subsistemas/interfaz-xr/interfaz/)).
- Prueba los movimientos a baja velocidad antes de pasar a una prueba de
  integración completa.

### Protocolo formal — pendiente

El proyecto original dejó esta tarea abierta, y sigue sin resolverse. Falta
acordar con el equipo cuatro cosas:

- El procedimiento de paro seguro.
- El checklist previo a cada prueba.
- Las zonas de operación.
- Las distancias mínimas de supervisión.

Ese protocolo no se redactó aquí. Inventar un procedimiento de seguridad
que nadie ha validado sería peor que declararlo pendiente.

## Solución de problemas

Esta tabla recoge las fallas que el proyecto ha visto con más frecuencia,
con su síntoma visible y el primer sitio donde conviene mirar. Está pensada
para consulta rápida durante una sesión, no como guía de diagnóstico
completa.

### Fallas comunes

| Caso | Síntoma | Causas probables | Qué revisar |
| --- | --- | --- | --- |
| No hay comunicación ZMQ | No llegan datos a XR | Red no válida, servicio no iniciado, puertos no disponibles | Estado del backend, red local, [puertos documentados](/sistema/arquitectura/comunicaciones/) |
| XR no recibe datos | Paneles vacíos o sin actualización | Suscripción inactiva, endpoint incorrecto | Configuración de endpoint, estado de tópicos |
| Robot no se mueve | Comando recibido sin acción física | Puente de control incompleto, firmware no ejecutando | Estado del ESP32-C3, alimentación, enlace de control |
| Un motor no responde | Movimiento parcial | Módulo embebido o conexión física | Cableado, módulo, señales de salida |
| ESP32-C3 no ejecuta firmware | Sin respuesta del módulo | Firmware ausente o despliegue incorrecto | Método de carga y arranque |
| Computadora no detecta dispositivo | Sensor/control no visible | Conexión física o driver | Puerto físico, enlace USB, estado del módulo |
| Movimiento físico no coincide con el virtual | Acción inconsistente | Mapeo parcial o falta de calibración | Configuración de control y referencias espaciales |
| Respuesta irregular o retraso | Control inestable | Carga de sistema, red o sincronización | Estado de red y consumo de recursos |

### Diagnóstico detallado — pendiente

Faltan dos piezas que el proyecto original ya identificaba: los
procedimientos de diagnóstico con comandos concretos por subsistema, y un
registro histórico de las fallas ya resueltas. Ninguna de las dos se redactó
para este sitio, porque exigen experiencia de operación que no está
documentada en ningún lado.

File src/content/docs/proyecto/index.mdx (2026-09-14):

---
title: Proyecto
description: "Qué es Remote Hands, qué se propone, qué cubre, qué lo limitó, qué debe cumplir y el vocabulario del sitio."
tableOfContents:
  minHeadingLevel: 2
  maxHeadingLevel: 2
---

import { Requirement } from '@project';

Todo lo que define el proyecto como proyecto, antes de entrar al robot: su propósito, sus objetivos, su alcance, las restricciones con las que se construyó, los requisitos que debe cumplir y el vocabulario que usa este sitio.

## Resumen

Remote Hands es un sistema robótico de operación remota para tareas
logísticas de última milla en centros de distribución local. Su propósito es
habilitar el teletrabajo de personas con discapacidad motriz: el operador
controla el robot desde una interfaz XR, sin necesidad de estar físicamente
en el almacén.

<figure>
  Manipulador montado sobre la plataforma móvil, formando el robot completo
  <figcaption>Remote Hands: un manipulador de 3 GDL sobre una plataforma móvil diferencial, teleoperado desde un visor de realidad mixta.</figcaption>
</figure>

El proyecto nace del cruce de dos tendencias. La primera es la demanda
logística creciente del comercio electrónico. La segunda es la baja
participación laboral formal de personas con discapacidad motriz, causada
por la falta de herramientas de trabajo adaptadas y no por falta de
capacidad. El desarrollo de ambas está en
[Contexto](/academico/#contexto) y
[Problemática](/academico/#problemática).

### Qué demuestra el prototipo

El prototipo es un robot móvil con manipulador de 3 GDL, operado desde una
Meta Quest y coordinado por una NUC embarcada. La arquitectura completa está
en [Sistema · Arquitectura](/sistema/arquitectura/resumen/).

Los tres subsistemas —robot móvil, servidor/percepción e interfaz XR— están
construidos y verificados por separado. La integración de control extremo a
extremo sigue en proceso; el estado real de cada uno está en la
[portada](/).

### Extensión académica

Este proyecto es además un *Proyecto Terminal* universitario, con marco de
investigación propio: pregunta de investigación, metodología de diseño de
ingeniería en cuatro fases y marco teórico sobre logística, discapacidad,
robótica de teleoperación y usabilidad. El detalle completo está en
[Documentación académica](/academico/#contexto).

Esa sección es una extensión de `@sebs/project-docs`, no parte del framework
genérico. Un proyecto de ingeniería sin componente académico —una PCB
personal, por ejemplo— no necesita pregunta de investigación ni marco
teórico, y no arrastra esas páginas.

## Objetivos

Los objetivos de abajo están transcritos del documento de Proyecto Terminal
tal como quedaron registrados. No se reescribieron para este sitio: cambiar
la redacción de un objetivo formal cambiaría lo que el proyecto se
comprometió a hacer.

### Objetivo general

Desarrollar un sistema robótico de operación remota orientado a tareas
logísticas de última milla en centros de distribución local, que permita el
teletrabajo de personas con discapacidad motriz.

### Objetivos específicos

**OE1 — Análisis de tareas.** Identificar y clasificar tareas logísticas
que puedan ejecutarse de forma remota, considerando su complejidad
operativa, requerimientos cognitivos y restricciones físicas.

**OE2 — Requerimientos de sistema.** Establecer los requerimientos
funcionales, operativos y de accesibilidad que debe cumplir un sistema de
operación remota para ser utilizable por personas con discapacidad motriz.

**OE3 — Integración técnica.** Desarrollar un sistema robótico teleoperado
que integre interacción humano-robot, alineado a los requerimientos de
accesibilidad y de tareas logísticas.

**OE4 — Validación experimental.** Evaluar el sistema diseñado mediante
métricas de usabilidad, comparándolo con procesos logísticos convencionales.

### Estado de avance

El desarrollo metodológico de los cuatro objetivos está en
[Metodología](/academico/#metodología).

**OE3** es el que más avance registra. Su estado real está en la
[portada](/) y en
[Sistema](/sistema/arquitectura/resumen/).

**OE4** corresponde a la Fase 4 de la metodología: validación experimental
con operadores y cuestionario SUS. La documentación migrada hasta ahora no
confirma que esas sesiones se hayan ejecutado, así que este sitio no afirma
que el objetivo esté cumplido. El único dataset experimental disponible es
el [experimento de
latencia](/latencia-wifi/#resultados),
que mide desempeño de red y no usabilidad.

## Alcance

El sistema cubre la integración completa de tres subsistemas: el diseño
mecánico y electrónico del robot, la interfaz de usuario XR, y el middleware
de coordinación.

### Qué incluye

- **Ejecución remota de tareas logísticas elementales.** El sistema
  mecatrónico integra mecanismos de manipulación y sistemas de
  visualización. Con ellos, el operador obtiene la conciencia situacional
  que la tarea requiere.
- **Estación de mando e interfaz centrada en el usuario.** Incluye
  adaptaciones para operarios con movilidad reducida en miembros inferiores.
  La usabilidad es el criterio de diseño prioritario.
- **Validación en laboratorio controlado**, orientada a demostrar la
  viabilidad de la interacción humano-máquina a distancia.

### Qué no incluye

La validación no se ejecuta en un almacén real en operación. El límite es
deliberado: el objetivo es demostrar la viabilidad de la interacción a
distancia, no medir el desempeño del sistema en una operación productiva.

### Relacionado

Las limitaciones técnicas concretas que condicionaron el diseño —materiales,
herramientas y componentes disponibles— están en
[Restricciones](/proyecto/#restricciones). El marco de
investigación completo está en [Documentación
académica](/academico/#contexto).

## Restricciones

Las restricciones de abajo están documentadas explícitamente en el proyecto
original; ninguna es una inferencia hecha para este sitio. Todas
condicionaron decisiones de diseño reales, y cada una enlaza a la página
donde se ve su efecto.

<figure>
  Drivers de motor y material electrónico disponible en el laboratorio
  <figcaption>Las restricciones del proyecto son en buena medida las del material disponible: lo que había en el laboratorio acotó el punto de partida.</figcaption>
</figure>

### Mecánica

- **Materiales.** Solo había lámina de acero calibre 18 (1,2 mm) y calibre
  24 (0,6 mm).
- **Herramientas.** El laboratorio disponía de cortadora láser y dobladora
  manual, sin acceso a doblado CNC. La dobladora manual impuso el límite
  real: cuando una pieza requería ángulos de doblez muy ajustados, se
  dividió en secciones unidas por tornillería en vez de fabricarse entera
  (ver
  [Manipulador](/sistema/subsistemas/robot-movil/manipulador/)).
- **Actuadores.** Los motores disponibles eran NEMA17 de stock. Su par
  nominal obligó a una reducción compuesta de 25:1 para alcanzar el torque
  que el manipulador necesita.

### Electrónica

- **Componentes de catálogo.** El driver de tracción debía ser compacto y
  replicable, sin depender de piezas de fuente única.
- **Corriente de tracción.** El objetivo era 4–5 A continuos con picos de
  hasta 8 A. Ese rango determinó la selección de MOSFETs del Puente H (ver
  [Electrónica](/sistema/subsistemas/robot-movil/electronica/)).

### Software

- **Sin ROS.** El proyecto descartó ROS por una decisión explícita de
  simplicidad y portabilidad, registrada en
  [ADR-0001](/registro/#adr-0001-la-nuc-como-coordinador-único).
- **Sin IP fija.** La red del laboratorio no asigna IP fija a la NUC. Esa
  limitación es la que obliga a buscar la IP en cada arranque, y define el
  paso 3 de la [puesta en
  marcha](/operacion/#puesta-en-marcha).

### Validación

- **Entorno de laboratorio.** La validación se ejecuta en laboratorio
  controlado, no en un almacén real en operación (ver
  [Alcance](/proyecto/#alcance)).
- **Latencia de referencia.** El umbral de 100 ms extremo a extremo procede
  de la literatura de teleoperación citada en el [marco
  teórico](/academico/#marco-teórico). El [experimento de
  latencia](/latencia-wifi/#resultados)
  mide solo un subconjunto de ese lazo —el protocolo MR-edge—, no el
  sistema físico completo.

## Requisitos de sistema

Los requisitos verificables del sistema, agrupados por seguridad, función, comunicación y desempeño. Cada uno nombra el subsistema responsable y su criterio de verificación, de modo que se pueda trazar contra la evidencia real del proyecto.

### Sobre el origen de estos requisitos

El proyecto original no mantenía requisitos formalizados como objetos
independientes. Vivían implícitos en el comportamiento documentado y
verificado de cada subsistema.

Los requisitos de abajo se derivaron de ese comportamiento real durante la
migración de la documentación. Son una **primera propuesta de
formalización**, no requisitos que el proyecto haya registrado en su
momento. Falta que el autor los revise y confirme, o corrija su prioridad y
su redacción.

### Seguridad

<Requirement id="REQ-SAF-001" subsystem="Robot móvil — Puente H" priority="must"
  verification="VER-PH-002" status="pass">
  El controlador de tracción debe arrancar en estado `DISARMED`, con la
  salida al motor deshabilitada, y requerir un comando `ARM` explícito antes
  de aceptar movimiento.
</Requirement>

<Requirement id="REQ-SAF-002" subsystem="Robot móvil — Puente H" priority="must"
  status="pass">
  Todo paquete de comando I²C con checksum inválido debe descartarse sin
  ejecutar movimiento; el motor conserva su último estado válido.
</Requirement>

<Requirement id="REQ-SAF-003" subsystem="Robot móvil — Gripper" priority="must"
  verification="VER-GRIP-002" status="pass">
  El controlador del gripper debe detener el motor en un máximo de 500&nbsp;ms
  si el encoder no registra cambio de posición mientras el motor está
  activo (detección de stall).
</Requirement>

### Movimiento

<Requirement id="REQ-MAN-001" subsystem="Robot móvil — Manipulador" priority="must"
  verification="VER-MAN-001" status="pass">
  El manipulador debe alcanzar el rango de movimiento de diseño en cada una
  de sus tres articulaciones: base −80° a +80°, codo 0° a 136,5°, muñeca
  −220° a 0°.
</Requirement>

<Requirement id="REQ-MAN-002" subsystem="Robot móvil — CL57T" priority="should"
  verification="VER-CL-002" status="pass">
  El sistema debe ejecutar una rutina de calibración (homing) por
  articulación al encender, sin intervención de la NUC.
</Requirement>

### Comunicación

<Requirement id="REQ-COM-001" subsystem="Servidor / percepción" priority="must" status="pass">
  El sistema debe separar video, sensores/estado y comandos en canales ZMQ
  independientes, de modo que desactivar el video no interrumpa el control
  ni la telemetría.
</Requirement>

<Requirement id="REQ-COM-002" subsystem="Servidor / percepción" priority="should"
  verification="EXP-LAT-001" status="pending">
  La latencia de protocolo (RTT) entre la interfaz XR y la NUC debe mantener
  un P95 por debajo de 100&nbsp;ms bajo la carga combinada de video y LiDAR
  en modo detallado.
</Requirement>

**REQ-COM-002 necesita confirmación.** Su umbral de 100 ms procede de la
literatura de teleoperación citada en el [marco
teórico](/academico/#marco-teórico), no de un valor que el
proyecto haya fijado. Se marca como `pending` por esa razón, no porque los
datos lo incumplan: el [experimento de
latencia](/latencia-wifi/#resultados)
midió un P95 máximo de 71,87 ms, por debajo del umbral en las siete
condiciones probadas.

### Trazabilidad

La matriz que cruza requisitos, subsistemas y verificaciones está pendiente.
Construirla exige cerrar antes la revisión de esta sección, porque no tiene
sentido trazar requisitos que todavía son una propuesta.

## Terminología

Cada término se define por lo que significa **en este proyecto**, que no
siempre coincide con su uso general en la industria.

| Término | Significado en este proyecto |
| --- | --- |
| **RTT** | Round-trip time: tiempo entre que Unity envía un `latency_probe` y recibe su `latency_ack`. No incluye latencia física del robot. |
| **ARMED / DISARMED** | Estados del firmware de tracción y CL57T. `DISARMED` deshabilita la salida al motor; `ARMED` la habilita. Arranca siempre en `DISARMED`. |
| **Homing** | Rutina de búsqueda de cero de una articulación usando su final de carrera — necesaria en cada encendido para el codo y la muñeca del manipulador. |
| **Stall** | Condición detectada cuando el encoder de un motor no cambia mientras el motor está activo — indica un obstáculo o límite mecánico. |
| **Deadtime** | Tiempo muerto forzado (300 µs en el Puente H) entre apagar una diagonal del puente H y activar la otra, para evitar cortocircuito. |
| **Daisy chain I²C** | Arquitectura maestro-esclavo del bus I²C: el Puente H maestro concentra la comunicación y reenvía a los nodos esclavos. |
| **NUC** | Computadora Intel i7 embarcada en el robot; coordinador único entre el operador y la electrónica de bajo nivel (ver [ADR-0001](/registro/#adr-0001-la-nuc-como-coordinador-único)). |
| **Warm-up** | Las primeras 10 muestras de cada corrida de latencia, descartadas del análisis estadístico por no representar condición estable de red. |
| **P95 / P99** | Percentil 95 / 99 de una distribución de latencia: el valor bajo el cual cae el 95 % / 99 % de las muestras. |
| **Jitter** | Desviación estándar de la latencia — variabilidad, no promedio. |
| **AGV** | Automated Guided Vehicle: la categoría industrial a la que pertenece esta plataforma. En estas páginas el término se reserva para hablar de esa categoría; al robot del proyecto se le llama siempre «robot móvil». |
| **GDL / DOF** | Grados de libertad (*degrees of freedom*). El manipulador tiene 3. En este sitio se escribe siempre **GDL**, no DOF. |

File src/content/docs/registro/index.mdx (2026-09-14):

---
title: Registro de ingeniería
description: "Las decisiones de arquitectura del proyecto, con su contexto y alternativas, y el estado real de cada pieza."
tableOfContents:
  minHeadingLevel: 2
  maxHeadingLevel: 2
---

Por qué el sistema está hecho así y en qué estado está cada pieza: las decisiones de arquitectura registradas y el estado verificado del proyecto.

## Decisiones

Cada decisión de arquitectura relevante se registra aquí como un ADR
—*Architecture Decision Record*—: un documento corto y fechado que explica
el contexto, las alternativas consideradas, lo que se decidió y qué costos
se aceptaron a cambio.

El registro existe para responder «¿por qué está hecho así?» sin depender de
la memoria de quien lo construyó. Una alternativa descartada, con su motivo,
vale tanto como la opción elegida: evita que alguien la reabra sin saber que
ya se evaluó.

### Decisiones registradas

| ID | Decisión | Estado |
| --- | --- | --- |
| [ADR-0001](/registro/#adr-0001-la-nuc-como-coordinador-único) | La NUC como coordinador único | Aceptada |

### Por qué solo hay una

El resto de las decisiones del proyecto se tomaron sin registrarse en su
momento. Reconstruirlas ahora corre el riesgo de inventar un razonamiento
que nadie tuvo, que es peor que no documentarlas.

Hay tres candidatas identificadas: la elección de ZeroMQ frente a otros
middleware, el reparto del control entre tres controladores embebidos, y el
uso de lámina doblada como método estructural. Cada una se documentará solo
si el autor confirma cuál fue el razonamiento real.

## ADR-0001: la NUC como coordinador único

**Estado:** aceptada · 2026 (Proyecto Terminal)

La decisión de arquitectura más determinante del proyecto: poner una NUC a bordo como único coordinador, en lugar de exponer el control de motores al operador remoto o de resolver la percepción en los microcontroladores. Este registro deja el contexto, las opciones consideradas y las consecuencias que se aceptaron.

### Contexto

El robot tiene que combinar tres exigencias que operan en escalas de tiempo
muy distintas:

| Exigencia | Escala de tiempo | Naturaleza |
| --- | --- | --- |
| Control de motores | Microsegundos a milisegundos | Determinista, sin margen para jitter |
| Percepción (LiDAR, cámara RGB-D) | Decenas de Hz | Intensiva en cómputo |
| Comunicación con el operador remoto | Latencia variable sobre WiFi | No fiable: admite pérdida de paquetes |

Ninguna arquitectura de un solo nivel de control resuelve bien las tres a la
vez: exponer el control de motores directamente al operador remoto
heredaría la incertidumbre de la red; resolver percepción y comunicación
dentro de los propios microcontroladores de motor los sobrecargaría con
responsabilidades ajenas a su función.

### Alternativas consideradas

**Control directo desde la Meta Quest a cada controlador embebido**, sin
computadora intermedia. Descartada por dos motivos. Expondría el control de
motores en tiempo real a la latencia y a la pérdida de paquetes de WiFi.
Además multiplicaría la lógica de protocolo que la interfaz XR tendría que
conocer: un protocolo por controlador, en lugar de un solo contrato ZMQ.

**ROS como middleware de coordinación.** Descartado por simplicidad y
portabilidad. El equipo prefirió un stack propio en Python 3.12 con ZeroMQ,
sin la sobrecarga de un framework de robótica completo para un sistema de
este tamaño.

**Un microcontrolador único como coordinador**, en lugar de una NUC.
Descartada por capacidad de cómputo: la percepción con RealSense y RPLiDAR,
más el streaming de video a la Meta Quest, exceden lo que un ESP32-C3 puede
sostener.

### Decisión

La **NUC actúa como coordinador único** entre el operador y la electrónica
embebida.

Recibe de la Meta Quest comandos simples por ZMQ —una velocidad deseada, un
ángulo objetivo— y coordina los sensores del robot. Después traduce esos
comandos a instrucciones para tres controladores ESP32-C3 independientes.

Cada controlador resuelve el control de bajo nivel de su propio subsistema
—tracción, manipulador o gripper— sin que la NUC intervenga en tiempo real.

### Consecuencias

**Favorables:**

- La interfaz XR se mantiene simple: habla un solo protocolo con un solo
  destino.
- El control de motores en tiempo real queda aislado de la variabilidad de
  WiFi. Vive enteramente sobre USB e I²C, que son deterministas.
- Los tres controladores embebidos se pueden reemplazar o extender por
  separado, sin tocar el resto del sistema.

**Costos aceptados:**

- La NUC es un punto único de coordinación. Si falla, el robot pierde todo
  el control remoto, porque el diseño actual no tiene coordinador
  redundante.
- Se renunció a un ecosistema de robótica maduro a cambio de un stack más
  simple y hecho a medida. Cualquier funcionalidad de ROS que haga falta en
  el futuro habrá que construirla.

### Estado

Aceptada y en producción. Es la arquitectura descrita en [Arquitectura del
sistema](/sistema/arquitectura/resumen/), y está verificada
sobre el robot construido.

## Estado actual

**Versión:** sin versionar formalmente · 2026 (Proyecto Terminal)

El proyecto original no llevaba un esquema de versionado formal, ni para
hardware ni para software. Esta sección describe por tanto el **estado real
verificado** de cada pieza, no una release numerada: asignar un número de
versión que nadie definió sería inventar información.

Adoptar un esquema de versionado hacia adelante es una decisión pendiente.

### Estado por pieza

La columna «Fuente» indica el documento del repositorio original de donde
procede cada estado.

| Pieza | Estado verificado | Fuente |
| --- | --- | --- |
| Plataforma móvil (mecánica) | Construida y probada | `03-robot-agv/plataforma-movil.md` |
| Manipulador 3 GDL (mecánica) | Construido y probado | `03-robot-agv/manipulador.md` |
| PCB Puente H (×2) | Diseñadas, ensambladas y probadas | `03-robot-agv/electronica.md` |
| PCB CL57T | Diseñada, ensamblada y probada | `03-robot-agv/controlador-cl57t.md` |
| Firmware Puente H (`main_movil_final.py`) | Funcional, 1 175 líneas | `03-robot-agv/sistemas-embebidos.md` |
| Firmware CL57T (`main_manipulador_final.py`) | Funcional, 933 líneas | `03-robot-agv/sistemas-embebidos.md` |
| Firmware gripper (`main_gripper_final.py`) | Funcional, 703 líneas | `03-robot-agv/sistemas-embebidos.md` |
| Stack NUC (Python 3.12 + ZMQ) | Funcional — ver detalle abajo | `03-robot-agv/software.md` |
| Integración XR → NUC → electrónica | En proceso | varias fuentes |

### Funcionalidad extremo a extremo

Estado en la última verificación registrada:

| Funcionalidad | Estado |
| --- | --- |
| Control de motores individual por USB-C | Verificado |
| Control por WiFi y BLE | Verificado |
| Integración de control de base desde interfaz XR | Funcional |
| Control completo del manipulador 3 GDL | Funcional |
| Control del gripper desde interfaz XR | Funcional |

### Próximo hito

Todavía sin definir. El propio proyecto original dejó cuatro candidatos
anotados en `11-pendientes.md`:

- PCB dedicada para el gripper, que reemplace el montaje actual en
  protoboard.
- Modelo cinemático del robot móvil, para odometría y trayectorias
  programadas.
- Cinemática inversa del manipulador.
- Captura de los encoders de tracción, para cerrar el lazo de control de
  velocidad.

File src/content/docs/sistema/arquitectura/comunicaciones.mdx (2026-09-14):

---
title: Comunicaciones del sistema
description: El contrato de comunicación completo — canales ZMQ, puertos, modos de sensor y el bus embebido entre la NUC y la electrónica.
---

import { InterfaceTable, ArchitectureDiagram } from '@project';

Remote Hands usa dos protocolos distintos, en dos capas separadas: **ZMQ
sobre WiFi** entre el operador y la NUC, y **USB/I²C** entre la NUC y la
electrónica embebida. Esta página es el contrato completo de las dos capas:
qué canal lleva qué, en qué dirección y por qué puerto.

<ArchitectureDiagram />

## Meta Quest ↔ NUC

En la capa inalámbrica, el sistema reparte la información en tres canales,
uno por responsabilidad, en lugar de multiplexarla sobre un socket único. La
razón es el aislamiento de fallos: video, sensores/estado y comandos pueden
degradarse o apagarse por separado sin arrastrar a los otros dos. Si el
video se reduce o se apaga, los comandos de control y la telemetría siguen
llegando.

<InterfaceTable
  caption="Canales ZMQ entre la Meta Quest y la NUC"
  columns={['Canal', 'Dirección', 'Contenido']}
  rows={[
    ['Video', 'NUC → Meta Quest', 'Frames de cámara comprimidos para visualización en XR'],
    ['Sensores / estado', 'NUC → Meta Quest', 'LiDAR, estado del sistema, confirmaciones de modo, telemetría'],
    ['Comandos', 'Meta Quest → NUC', 'Órdenes de movimiento, manipulador, video y modos de sensores'],
  ]}
/>

### Puertos ZMQ verificados

Los números de puerto están verificados contra el simulador de latencia
WF-IoT, que reproduce los canales, las frecuencias y los tamaños de payload
del sistema real. El montaje completo está en el [protocolo del
experimento](/latencia-wifi/#protocolo).

<InterfaceTable
  caption="Puertos ZMQ — verificados contra el simulador de latencia"
  columns={['Puerto', 'Socket', 'Dirección', 'Contenido']}
  rows={[
    ['5002', 'SUB bind', 'Quest → PC/NUC', 'Comandos JSON (tópico `cmd`)'],
    ['5001', 'PUB bind', 'PC/NUC → Quest', '`latency_ack`, `stat`, `mode_ack`, `lidar_grid`'],
    ['5555', 'PUB bind', 'PC/NUC → Quest', '`video_rgb` (bytes JPEG)'],
    ['5007', 'PUB bind', 'PC/NUC → Quest', 'Reservado — datos binarios'],
  ]}
/>

### Modos de LiDAR

La Meta Quest tampoco recibe todos los datos todo el tiempo. El operador
elige un modo de transmisión y el robot envía solo la resolución que esa
tarea necesita.

<InterfaceTable
  caption="Payload por modo de LiDAR, medido durante el experimento de latencia"
  columns={['Modo', 'Frecuencia', 'Payload (JSON)']}
  rows={[
    ['detail', '12 Hz', '120 122 bytes'],
    ['medium', '8 Hz', '480 122 bytes'],
    ['panorama', '4 Hz', '1 080 124 bytes'],
  ]}
/>

En las pruebas de latencia, el video se sustituye por JPEG sintético de
640×480 con calidad 85. Cada frame pesa 9 756 bytes de media, a 30 fps.
Viaja por el mismo canal que el video real (`5555`) y tiene su mismo orden
de magnitud, así que la carga que impone sobre la red es representativa.

## NUC ↔ electrónica embebida

```text
NUC
 └── COM4 (USB) ──► Puente H maestro
                        ├── I²C 0x08 ──► Puente H esclavo (motor base)
                        └── I²C 0x0B ──► Controlador CL57T (3 ejes)
 └── COM5 (USB) ──► Controlador gripper (directo, fuera del bus I²C)
 └── COM3 (USB) ──► RPLiDAR C1 (460 800 baud)
 └── USB3       ──► Intel RealSense D435i
```

El Puente H maestro concentra el bus I²C, así que la NUC controla tres nodos
de movimiento —tracción propia, tracción esclava y manipulador— con un solo
canal USB.

El gripper queda fuera de ese bus a propósito. Es el único controlador sin
PCB dedicada, y aislarlo en su propio canal serie simplifica el diagnóstico
cuando falla.

## Por qué dos protocolos y no uno

Cada capa tiene exigencias distintas, y ningún protocolo las cubre bien a la
vez.

WiFi con ZMQ tolera pérdida de paquetes y variación de latencia. Eso es
aceptable para telemetría y video, donde un frame perdido no compromete
nada. USB e I²C son deterministas y de baja latencia, que es justo lo que el
control de motores en tiempo real necesita.

Unificar ambas capas en un solo canal habría costado en cualquiera de las
dos direcciones. Poner el control de motores sobre WiFi le habría heredado
la incertidumbre de la red; poner la telemetría sobre USB habría cargado el
canal determinista con tráfico que no lo necesita.

El reparto de responsabilidades que se deriva de esto está registrado en
[ADR-0001](/registro/#adr-0001-la-nuc-como-coordinador-único).
Para una consulta rápida de puertos y tópicos sin la justificación, está
[Referencia · Comunicación](/sistema/arquitectura/comunicaciones/).

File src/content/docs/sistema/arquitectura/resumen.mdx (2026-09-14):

---
title: Sistema
description: Remote Hands completo — qué es, cómo opera, cómo se conectan el visor y el robot, y cómo se reparten las responsabilidades.
# Bloques grandes en el índice de la página: Sinopsis y Arquitectura.
tableOfContents:
  minHeadingLevel: 2
  maxHeadingLevel: 2
---

import { InterfaceTable, SignalChain } from '@project';

El sistema tiene dos elementos principales: **el robot móvil con
manipulador** y **la aplicación XR en Meta Quest 3**. Desde el visor, el
operador maneja el robot, consulta los sensores y elige qué datos quiere
recibir.

## Sinopsis

### Qué es

Un sistema de teleoperación móvil. El operador no está junto al robot: lo
ve y lo mueve a distancia, a través de la red WiFi.

<InterfaceTable
  caption="Elementos del sistema"
  columns={['Elemento', 'Qué hace']}
  rows={[
    ['Meta Quest 3', 'Interfaz de usuario: video, sensores y controles en realidad mixta'],
    ['Robot', 'Plataforma móvil con manipulador de 3 GDL y gripper'],
    ['NUC, a bordo del robot', 'Coordina: recibe las órdenes, lee los sensores y reparte el trabajo'],
    ['Placas embebidas', 'Tres controladores ESP32-C3 que mueven los motores en tiempo real'],
  ]}
/>

Cada elemento tiene su página: [Meta Quest
3](/sistema/subsistemas/interfaz-xr/),
[Robot](/sistema/subsistemas/robot-movil/),
[NUC](/sistema/subsistemas/servidor-percepcion/) y
[Embebidos](/sistema/subsistemas/robot-movil/firmware/).

### Cómo funciona

Un ciclo típico de operación:

1. El operador usa el visor para activar video, seleccionar la resolución
   del LiDAR o mover el robot.
2. La aplicación XR envía un comando ZMQ hacia la NUC.
3. La NUC interpreta el comando y decide qué hacer con él: cambiar un modo
   de sensor, transmitir video o pasar una orden a las placas embebidas.
4. Si el comando implica movimiento, la NUC lo envía a la placa
   correspondiente por USB o, a través del Puente H maestro, por I²C.
5. Las placas ejecutan el control local —interpolación de pasos, rampas,
   PWM— sin que la NUC gestione señales en tiempo real.
6. Los sensores capturan el entorno, y la NUC devuelve al visor solo los
   datos que el operador pidió.

Esa última parte importa: el robot solo transmite lo que el operador tiene
abierto, en lugar de saturar la red con todo lo que produce.

### Conexiones

<SignalChain
  porFila={2}
  pasos={[
    { nombre: 'Meta Quest 3', detalle: 'interfaz de usuario', imagen: '/images/3d/meta-quest-3.webp' },
    { nombre: 'Robot', detalle: 'manipulación móvil', imagen: '/images/3d/robot.webp' },
  ]}
  enlaces={[
    {
      medio: 'ZMQ por WiFi',
      vuelta: 'Video 740 × 680 px · LiDAR 100 × 100 px',
      ida: 'Joints = [q1, q2, qb] · Mov = [±255, ±255]',
    },
  ]}
/>

Cada tipo de dato viaja por su propio puerto ZeroMQ; el contrato completo
está en [Comunicaciones](/sistema/arquitectura/comunicaciones/).

## Arquitectura

### Reparto de responsabilidades

La **NUC actúa como coordinador**. Los demás elementos ejecutan las tareas
de bajo nivel: control de motores, PWM, rampas, señales de drivers y rutinas
de calibración. Esa división mantiene simples los comandos que salen de la
interfaz XR, porque toda la complejidad del movimiento se resuelve dentro
del robot.

| Capa | Responsabilidad |
| --- | --- |
| Meta Quest 3 | Operación, visualización, selección de modos |
| NUC | Coordinación general, sensores, streaming, comunicación ZMQ |
| ESP32-C3 (×3) | Control embebido de bajo nivel |
| Placas de diseño propio | Adaptación eléctrica, control de motores, señales para drivers |
| Sensores | Percepción del entorno: LiDAR y cámara RGB-D |

### Sin ROS

El sistema no usa ROS. Fue una decisión explícita, tomada por simplicidad y
portabilidad, y está registrada junto al resto de la arquitectura en
[ADR-0001](/registro/#adr-0001-la-nuc-como-coordinador-único).

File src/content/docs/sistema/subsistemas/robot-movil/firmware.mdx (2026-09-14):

---
title: Embebidos
description: Las tres placas ESP32-C3 que mueven los motores del robot — qué son, cómo se reparten el trabajo, cómo se conectan y su firmware.
# Bloques grandes en el índice de la página: Sinopsis y Firmware.
tableOfContents:
  minHeadingLevel: 2
  maxHeadingLevel: 2
---

import { Artifact, SignalHub } from '@project';

<figure>
  Los dos módulos Puente H, el controlador CL57T y el controlador del gripper
</figure>

Los embebidos son las placas que mueven los motores del robot. La NUC les
manda consignas simples y cada una genera las señales que su hardware
necesita, en tiempo real.

## Sinopsis

### Qué es

Tres controladores, todos con un **ESP32-C3 SuperMini** y firmware
**MicroPython**. Cada uno resuelve una función de actuación distinta y tiene
su propia página.

| Controlador | Placa | Comunicación con la NUC | Función |
| --- | --- | --- | --- |
| [Puente H](/sistema/subsistemas/robot-movil/electronica/) ×2 | Diseño propio (KiCad) | USB-CDC COM4 (maestro) | Motores DC de tracción |
| [Controlador CL57T](/sistema/subsistemas/robot-movil/controladores/cl57t/) | Diseño propio (KiCad) | I²C `0x0B`, vía el maestro | 3 ejes del manipulador |
| [Gripper](/sistema/subsistemas/robot-movil/controladores/gripper/) | Sin PCB, cableado a mano | USB-CDC COM5 | Pinza, por posición en mm |

### Cómo funciona

El Puente H configurado como maestro (`DIP = 100`) concentra el bus I²C: la
NUC le manda por un solo USB las órdenes de tracción y del brazo, y él las
reparte. Ese trío forma el [Conjunto
I²C](/sistema/subsistemas/robot-movil/conjunto-i2c/). El gripper queda fuera
del bus, con su propio USB.

Las tres placas conservan el USB-C del ESP32-C3 como interfaz de depuración,
siempre disponible.

### Conexiones

<SignalHub
  centro={{ nombre: 'NUC', detalle: 'coordinador', imagen: '/images/3d/nuc.webp' }}
  ramas={[
    {
      nombre: 'Puente H ×2',
      detalle: 'maestro y esclavo, un motor cada uno',
      imagen: '/images/3d/puente-h.webp',
      href: '/sistema/subsistemas/robot-movil/electronica/',
      enlace: { medio: 'USB-CDC · COM4, al maestro', ida: 'tracción · POSE', vuelta: 'estado' },
    },
    {
      nombre: 'Controlador CL57T',
      detalle: 'base, codo y muñeca',
      imagen: '/images/3d/controlador-cl57t.webp',
      enlace: { medio: 'COM4 → I²C 0x0B', ida: 'texto ASCII', vuelta: 'OK …' },
    },
    {
      nombre: 'Controlador del gripper',
      detalle: 'pinza',
      imagen: '/images/3d/controlador-gripper.webp',
      enlace: { medio: 'USB-CDC · COM5', ida: 'm <mm>', vuelta: 'GRIPPER_STATE' },
    },
  ]}
/>

## Firmware

Los tres firmwares, completos. El protocolo, los parámetros y el detalle de
cada uno están en la página de su placa.

<Artifact href="/firmware/main_movil_final.py" name="Firmware de tracción — main_movil_final.py" />
<Artifact href="/firmware/main_manipulador_final.py" name="Firmware del manipulador — main_manipulador_final.py" />
<Artifact href="/firmware/main_gripper_final.py" name="Firmware del gripper — main_gripper_final.py" />

| Firmware | Controlador | Líneas |
| --- | --- | ---: |
| `main_movil_final.py` | Puente H | 1 175 |
| `main_manipulador_final.py` | Controlador CL57T | 933 |
| `main_gripper_final.py` | Gripper | 703 |

Del lado de la NUC, lo que manda sobre estas placas es el coordinador,
documentado en [NUC](/sistema/subsistemas/servidor-percepcion/).

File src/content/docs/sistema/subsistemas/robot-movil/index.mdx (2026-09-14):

---
title: Robot
description: El robot de Remote Hands — qué es, cómo se reparte el control entre sus partes y cómo se conectan.
# Bloques grandes en el índice de la página: Sinopsis y Partes.
tableOfContents:
  minHeadingLevel: 2
  maxHeadingLevel: 2
---

import { InterfaceTable, SignalHub } from '@project';

<figure>
  Robot completo: el manipulador sobre la plataforma móvil
</figure>

El robot es la parte de Remote Hands que se mueve: una plataforma móvil que
lo desplaza por el piso y un manipulador que toma objetos. La NUC que lleva
a bordo recibe las órdenes del operador y las reparte entre sus placas.

## Sinopsis

### Qué es

Dos piezas construidas por caminos distintos: una **plataforma móvil
diferencial rehabilitada** y un **manipulador de 3 GDL construido desde
cero**. Sobre ellas van los sensores que ven el entorno y las placas
embebidas que mueven los motores.

<InterfaceTable
  caption="Partes del robot"
  columns={['Parte', 'Qué hace']}
  rows={[
    ['Plataforma móvil', 'Tracción diferencial con dos motores DC'],
    ['Manipulador', 'Brazo de 3 GDL con gripper lineal'],
    ['Embebidos', 'Tres controladores ESP32-C3: tracción, brazo y gripper'],
    ['Sensores', 'LiDAR y cámara RGB-D para la percepción; finales de carrera para el brazo'],
  ]}
/>

### Cómo funciona

Cada parte resuelve su propio movimiento de bajo nivel con un controlador
embebido dedicado. La NUC solo les envía consignas simples —una velocidad
para la base, un ángulo por eje, una apertura en milímetros— y cada placa
genera las señales que su hardware necesita: PWM, pulsos de paso, rampas y
rutinas de homing.

Ese reparto mantiene simples los comandos que salen del visor: toda la
complejidad del movimiento se resuelve dentro del robot. Está descrito en
[Sistema](/sistema/arquitectura/resumen/).

### Conexiones

La NUC es el centro del robot. Los sensores y las placas se conectan a ella
por USB; los motores cuelgan de las placas.

<SignalHub
  centro={{ nombre: 'NUC', detalle: 'a bordo · Intel i7', imagen: '/images/3d/nuc.webp' }}
  ramas={[
    {
      nombre: 'Sensores',
      detalle: 'RealSense D435i y RPLiDAR C1',
      imagen: '/images/3d/rplidar-c1.webp',
      lado: 'entrada',
      enlace: { medio: 'USB 3 · COM3', vuelta: 'video · barridos 2D' },
    },
    {
      nombre: 'Plataforma móvil',
      detalle: 'vía Puente H maestro',
      imagen: '/images/3d/base-diferencial.webp',
      enlace: { medio: 'USB-CDC · COM4', ida: 'consigna por motor' },
    },
    {
      nombre: 'Manipulador',
      detalle: 'vía Puente H maestro y CL57T',
      imagen: '/images/3d/manipulador.webp',
      enlace: { medio: 'COM4 → I²C 0x0B', ida: 'POSE base codo muñeca', vuelta: 'estado' },
    },
    {
      nombre: 'Gripper',
      detalle: 'controlador propio',
      imagen: '/images/3d/gripper.webp',
      enlace: { medio: 'USB-CDC · COM5', ida: 'apertura en mm', vuelta: 'GRIPPER_STATE' },
    },
  ]}
/>

La plataforma y el manipulador comparten un solo USB: el Puente H maestro
recibe las dos órdenes y reenvía la del brazo por I²C. Es el [Conjunto
I²C](/sistema/subsistemas/robot-movil/conjunto-i2c/).

## Partes

Cada parte tiene su página:

- **[Plataforma móvil](/sistema/subsistemas/robot-movil/plataforma-movil/)**:
  la base rehabilitada, su tracción y su unión con el manipulador.
- **[Manipulador](/sistema/subsistemas/robot-movil/manipulador/)**: la
  cinemática, la transmisión, la manufactura por corte láser y los planos.
- **[Embebidos](/sistema/subsistemas/robot-movil/firmware/)**: los tres
  controladores ESP32-C3 y su firmware, con una página por placa: [Puente
  H](/sistema/subsistemas/robot-movil/electronica/), [Controlador
  CL57T](/sistema/subsistemas/robot-movil/controladores/cl57t/) y
  [Gripper](/sistema/subsistemas/robot-movil/controladores/gripper/).
- **[Sensores](/sistema/subsistemas/robot-movil/sensores/)**: dónde van los
  sensores de percepción y los finales de carrera.

Los resultados de prueba de todo el robot están en
[Verificación](/sistema/subsistemas/robot-movil/verificacion/).

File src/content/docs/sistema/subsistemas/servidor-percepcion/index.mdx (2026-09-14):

---
title: NUC
description: La computadora a bordo del robot — qué es, cómo coordina el sistema, con qué se conecta y el software que corre.
# Bloques grandes en el índice de la página: Sinopsis y Software.
tableOfContents:
  minHeadingLevel: 2
  maxHeadingLevel: 2
---

import { InterfaceTable, Artifact, SignalHub } from '@project';

<figure>
  Intel NUC, la computadora a bordo del robot
</figure>

La NUC es la computadora del robot. Recibe las órdenes del operador, lee
los sensores y reparte el trabajo entre las placas embebidas que mueven los
motores.

## Sinopsis

### Qué es

Una **Intel NUC i7** que viaja a bordo del robot: pese al nombre de la
sección, no hay ningún servidor externo. Sobre ella corre un único proceso
en **Python 3.12 con ZeroMQ**, sin ROS. Dejar fuera ROS fue una decisión
deliberada, registrada en
[ADR-0001](/registro/#adr-0001-la-nuc-como-coordinador-único).

Ese proceso hace dos trabajos, cada uno documentado en su página:

- **[Middleware ZMQ](/sistema/subsistemas/servidor-percepcion/middleware/)**:
  los cuatro canales con el visor y los dos puentes serie hacia las placas.
- **[Percepción](/sistema/subsistemas/servidor-percepcion/percepcion/)**:
  el grid y las paredes del LiDAR, y el video y la visión de la RealSense.

### Cómo funciona

La NUC procesa solo lo que el modo activo requiere —visión YOLO, grid de
LiDAR o pipeline de paredes—, de modo que un modo inactivo no consume ni CPU
ni red.

Tampoco reenvía los comandos tal cual: los traduce. Un `drive_cmd` con
velocidades `v`/`w` del modelo uniciclo se convierte en consignas por motor
antes de salir por COM4, y un `manip_cmd` en grados se convierte en la trama
ASCII `POSE` que entiende el [Controlador
CL57T](/sistema/subsistemas/robot-movil/controladores/cl57t/). El control en
tiempo real —pasos, rampas, PWM— se queda en las placas.

### Conexiones

Todo lo que entra y sale de la NUC. A la izquierda, lo que le llega: las
órdenes del operador y lo que miden los sensores. A la derecha, las placas a
las que manda. Las puntas de cada línea señalan hacia dónde viaja la
información, y lo que viaja se lee debajo con la misma flecha.

<SignalHub
  centro={{ nombre: 'NUC', detalle: 'Intel i7 · Python 3.12', imagen: '/images/3d/nuc.webp' }}
  ramas={[
    {
      nombre: 'Meta Quest 3',
      href: '/sistema/subsistemas/interfaz-xr/',
      detalle: 'interfaz de usuario',
      imagen: '/images/3d/meta-quest-3.webp',
      lado: 'entrada',
      enlace: { medio: 'ZMQ por WiFi', vuelta: '5002 comandos', ida: '5555 video · 5001 estado · 5007 paredes' },
    },
    {
      nombre: 'RealSense D435i',
      href: '/sistema/subsistemas/robot-movil/sensores/realsense-d435i/',
      detalle: 'cámara RGB-D',
      imagen: '/images/3d/realsense-d435.webp',
      lado: 'entrada',
      enlace: { medio: 'USB 3', vuelta: 'RGB 640 × 480 · profundidad' },
    },
    {
      nombre: 'RPLiDAR C1',
      href: '/sistema/subsistemas/robot-movil/sensores/rplidar-c1/',
      detalle: 'LiDAR 2D',
      imagen: '/images/3d/rplidar-c1.webp',
      lado: 'entrada',
      enlace: { medio: 'COM3 · 460 800 baud', vuelta: 'barridos 2D' },
    },
    {
      nombre: 'Conjunto I²C',
      href: '/sistema/subsistemas/robot-movil/conjunto-i2c/',
      detalle: 'Puente H ×2 y CL57T',
      imagen: '/images/3d/puente-h.webp',
      enlace: { medio: 'USB-CDC · COM4', ida: 'tracción · POSE', vuelta: 'estado' },
    },
    {
      nombre: 'Controlador del gripper',
      href: '/sistema/subsistemas/robot-movil/controladores/gripper/',
      detalle: 'ESP32-C3',
      imagen: '/images/3d/controlador-gripper.webp',
      enlace: { medio: 'USB-CDC · COM5', ida: 'm <mm>', vuelta: 'GRIPPER_STATE' },
    },
  ]}
/>

Por COM4 la NUC habla solo con el Puente H maestro, que reenvía por I²C al
Puente H esclavo y al controlador CL57T: es el [Conjunto
I²C](/sistema/subsistemas/robot-movil/conjunto-i2c/). El gripper queda fuera
de ese bus, con su propio USB.

## Software

<Artifact href="/software/nuc_master_code.py" name="Coordinador de la NUC — nuc_master_code.py" />

### Cómo se ejecuta

El coordinador es un único proceso de Python que abre los cuatro puertos
ZeroMQ, conecta los sensores y mantiene los dos puentes serie. No hay
orquestador ni servicio: se lanza a mano.

<InterfaceTable
  caption="Dependencias del coordinador"
  columns={['Paquete', 'Para qué', 'Nota']}
  rows={[
    ['pyzmq', 'Los cuatro canales ZeroMQ', 'Núcleo del middleware'],
    ['opencv-python', 'Compresión JPEG y morfología del pipeline de paredes', 'Se importa como cv2'],
    ['numpy', 'Grids, máscaras y nubes de puntos', '—'],
    ['pyrealsense2', 'RealSense D435i', 'Requiere el SDK de Intel instalado'],
    ['ultralytics', 'YOLO en los modos pose y segmentación', 'Descarga los pesos la primera vez'],
    ['pyserial', 'Puentes COM4 y COM5', 'Import opcional: sin él, el arranque no falla'],
    ['rplidarc1', 'RPLiDAR C1', 'Con respaldo a un módulo scanner local'],
  ]}
/>

El código tolera que falten `pyserial` y el módulo del LiDAR: los envuelve en
`try`/`except` y arranca igual, sin ese periférico. Eso permite desarrollar
la parte de percepción o de red sin el robot conectado. Sin la RealSense y
el RPLiDAR, el proceso arranca, pero se queda sin percepción.

### Puertos fijos

Los puertos serie están **fijados en el código** (`COM4`, `COM5`, `COM3`),
no son configurables por argumento ni por variable de entorno. En otra
máquina hay que editarlos, igual que los puertos ZeroMQ: `5555`, `5001`,
`5002` y `5007`.

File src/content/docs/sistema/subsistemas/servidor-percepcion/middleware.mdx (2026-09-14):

---
title: Middleware ZMQ
description: Los canales entre la NUC y el visor, y los puentes serie hacia las placas — qué es, cómo funciona, con qué se conecta y su protocolo.
# Bloques grandes en el índice de la página: Sinopsis y Protocolo.
tableOfContents:
  minHeadingLevel: 2
  maxHeadingLevel: 2
---

import { ParameterTable, InterfaceTable, Artifact, SignalHub } from '@project';

El middleware es la parte del coordinador de la NUC que mueve mensajes: los
cuatro canales ZeroMQ con el visor y los dos puentes serie hacia las placas
embebidas.

## Sinopsis

### Qué es

Código dentro del coordinador de la NUC, no un programa aparte. Abre
**cuatro puertos ZeroMQ**, uno por tipo de dato, y mantiene dos puertos serie.
Esta página lo describe desde dentro de la NUC; el contrato entre
subsistemas, con la tabla de puertos verificados, está en [Comunicaciones del
sistema](/sistema/arquitectura/comunicaciones/#puertos-zmq-verificados).

<InterfaceTable
  caption="Puertos ZMQ del middleware de la NUC"
  columns={['Puerto', 'Rol NUC', 'Rol Unity', 'Tipo']}
  rows={[
    ['5555', 'PUB', 'SUB', 'Video: frames JPEG comprimidos'],
    ['5001', 'PUB', 'SUB', 'Sensores y estado: JSON por tópico'],
    ['5002', 'SUB', 'PUB', 'Comandos desde Unity hacia la NUC'],
    ['5007', 'PUB', 'SUB', 'Paredes y puntos LiDAR: datos binarios'],
  ]}
/>

<Artifact href="/software/nuc_master_code.py" name="Coordinador de la NUC — nuc_master_code.py" />

### Cómo funciona

Tres decisiones de diseño gobiernan el reparto:

- **Puertos separados por tipo de dato.** El video y los datos binarios no
  pueden bloquear el canal JSON, que es el que lleva el estado y los
  comandos.
- **Streaming selectivo.** Cada modo publica solo mientras está activo, así
  que un sensor apagado no cuesta ni CPU ni ancho de banda.
- ***High watermark* por canal.** Cada puerto tiene su propio límite de cola,
  y la diferencia entre ellos es deliberada.

<ParameterTable
  caption="High watermark de envío por canal"
  rows={[
    { parameter: 'Video (5555)', value: '2', unit: 'mensajes', notes: 'Un frame viejo no sirve: mejor descartarlo que acumular retraso' },
    { parameter: 'Sensores y estado (5001)', value: '300', unit: 'mensajes', notes: 'JSON pequeño; conviene no perder eventos de estado' },
    { parameter: 'Paredes y puntos (5007)', value: '50', unit: 'mensajes', notes: 'Punto medio: paquetes grandes, pero tolera algo de cola' },
  ]}
/>

El límite de **2** en video es lo que mantiene la teleoperación utilizable.
Con una cola profunda, el operador vería frames cada vez más viejos conforme
la red se degrada, en lugar de perder algunos y seguir viendo el presente.

### Conexiones

Los canales que el middleware atiende: ZeroMQ hacia el visor y serie hacia
las dos placas que reciben órdenes directas de la NUC.

<SignalHub
  centro={{ nombre: 'NUC', detalle: 'coordinador · Python 3.12', imagen: '/images/3d/nuc.webp' }}
  ramas={[
    {
      nombre: 'Meta Quest 3',
      detalle: 'cliente Unity',
      imagen: '/images/3d/meta-quest-3.webp',
      lado: 'entrada',
      enlace: { medio: 'ZMQ por WiFi', vuelta: '5002 · cmd JSON', ida: '5555 · 5001 · 5007' },
    },
    {
      nombre: 'Puente H maestro',
      detalle: 'tracción y manipulador',
      imagen: '/images/3d/puente-h.webp',
      enlace: { medio: 'COM4 · 115 200 baud', ida: 'POSE {base} {codo} {muneca}', vuelta: 'estado' },
    },
    {
      nombre: 'Controlador del gripper',
      detalle: 'pinza',
      imagen: '/images/3d/controlador-gripper.webp',
      enlace: { medio: 'COM5 · 115 200 baud', ida: 'm {mm}', vuelta: 'GRIPPER_STATE' },
    },
  ]}
/>

## Protocolo

### Tópicos JSON (puerto 5001)

| Tópico | Frecuencia | Contenido |
| --- | --- | --- |
| `stat` | ~2 Hz | Estado global: sensores OK, modos activos, ángulos del manipulador, `gripper_mm` |
| `mode_ack` | Al cambiar modo | Confirmación de cambio de modo |
| `lidar_grid` | ~12 Hz | Grid de ocupación linealizado del modo activo |
| `manip_state` | ~4 Hz | Ángulos actuales del manipulador y finales de carrera |
| `gripper_state` | ~4 Hz | Posición del gripper en mm, `busy`, `calibrated` |
| `vision` | ~10 Hz | Resultados YOLOv8 (pose o segmentación) |
| `cam_info` | Continuo | Intrínsecos de la RealSense y escala de profundidad |

### Comandos (puerto 5002)

Todos los comandos viajan como JSON. Estos son los más relevantes, agrupados
por función:

| Familia | Ejemplo |
| --- | --- |
| Modo de percepción | `{"type": "set_camera_mode", "mode": "normal\|pose\|segment\|off"}` |
| Habilitar control | `{"type": "master_arm"}` / `{"type": "master_disarm"}` / `{"type": "stop_all"}` |
| Base móvil | `{"type": "drive_cmd", "v": 0.5, "w": -0.3, "enabled": true}` |
| Manipulador | `{"type": "manip_cmd", "q": [base_deg, codo_deg, muneca_deg]}` |
| Gripper | `{"type": "gripper_cmd", "opening_mm": 30.0}` |

`drive_cmd` usa modelo uniciclo: la NUC mezcla `v`/`w` y envía al Puente H
maestro a 15 Hz.

### Mando y seguridad

<ParameterTable
  caption="Valores que gobiernan el mando y sus paros"
  rows={[
    { parameter: 'Envío de tracción al maestro', value: '15', unit: 'Hz' },
    { parameter: 'Timeout de drive_cmd', value: '0,35', unit: 's', notes: 'Sin comando nuevo, la tracción se detiene' },
    { parameter: 'Zona muerta del joystick', value: '0,08', unit: '—', notes: 'Evita deriva por reposo impreciso del control' },
    { parameter: 'Consigna máxima al puente H', value: '255', unit: 'crudo' },
    { parameter: 'Timeout de heartbeat de comandos', value: '2,0', unit: 's' },
    { parameter: 'Consulta de estado al manipulador', value: '4', unit: 'Hz' },
    { parameter: 'Consulta de estado al gripper', value: '4', unit: 'Hz' },
    { parameter: 'Envío de comandos al gripper', value: '20', unit: 'Hz' },
    { parameter: 'Reintento de reconexión serie', value: '1,0', unit: 's' },
  ]}
/>

Los dos timeouts cubren fallos distintos. El de `drive_cmd` (0,35 s) actúa
cuando el operador deja de mandar pero la conexión sigue viva. El de
heartbeat (2 s) actúa cuando se cae el enlace entero.

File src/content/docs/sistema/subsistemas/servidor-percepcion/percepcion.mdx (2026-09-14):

---
title: Percepción
description: Cómo la NUC procesa el LiDAR y la cámara RGB-D — qué es, cómo funciona, con qué se conecta y el detalle de cada pipeline.
# Bloques grandes en el índice de la página: Sinopsis, RPLiDAR C1 y RealSense D435i.
tableOfContents:
  minHeadingLevel: 2
  maxHeadingLevel: 2
---

import { ParameterTable, Artifact, SignalHub } from '@project';

<figure>
  La cámara Intel RealSense D435i y el RPLiDAR C1
</figure>

La percepción es lo que la NUC hace con sus dos sensores: un mapa 2D del
entorno con el LiDAR, y video y visión por computadora con la cámara RGB-D.
El resultado viaja al visor por ZeroMQ.

## Sinopsis

### Qué es

Dos pipelines independientes dentro del coordinador de la NUC, uno por
sensor.

<ParameterTable
  caption="Sensores"
  rows={[
    { parameter: 'RPLiDAR C1', value: 'COM3', unit: '460 800 baud', notes: 'Grid de ocupación 2D, paredes, puntos' },
    { parameter: 'Intel RealSense D435i', value: 'USB3', unit: '—', notes: 'Video RGB al XR, profundidad calibrada, visión' },
  ]}
/>

Las características de cada sensor y cómo probarlo desde una PC están en su
página: [RPLiDAR C1](/sistema/subsistemas/robot-movil/sensores/rplidar-c1/) y
[RealSense D435i](/sistema/subsistemas/robot-movil/sensores/realsense-d435i/).

<Artifact href="/software/nuc_master_code.py" name="Coordinador de la NUC — nuc_master_code.py" />

### Cómo funciona

Cada pipeline trabaja solo cuando el operador tiene abierto el modo que lo
usa. El grid del LiDAR alimenta los paneles 2D del visor; las paredes y los
puntos alimentan la escena 3D; el video y la visión, el panel central.

La profundidad nunca sale en crudo: antes se corrige con una curva de
calibración, y la de cada detección se promedia en un disco de píxeles en
lugar de leerse de uno solo.

### Conexiones

<SignalHub
  centro={{ nombre: 'NUC', detalle: 'pipelines de percepción', imagen: '/images/3d/nuc.webp' }}
  ramas={[
    {
      nombre: 'RPLiDAR C1',
      detalle: 'LiDAR 2D',
      imagen: '/images/3d/rplidar-c1.webp',
      lado: 'entrada',
      enlace: { medio: 'COM3 · 460 800 baud', vuelta: 'barridos 2D' },
    },
    {
      nombre: 'RealSense D435i',
      detalle: 'cámara RGB-D',
      imagen: '/images/3d/realsense-d435.webp',
      lado: 'entrada',
      enlace: { medio: 'USB 3', vuelta: 'RGB 640 × 480 · profundidad' },
    },
    {
      nombre: 'Meta Quest 3',
      detalle: 'paneles y escena 3D',
      imagen: '/images/3d/meta-quest-3.webp',
      enlace: { medio: 'ZMQ por WiFi', ida: '5555 video · 5001 grid y visión · 5007 paredes y puntos' },
    },
  ]}
/>

## RPLiDAR C1

### Grid de ocupación

El grid tiene tres modos, con celda fija de 1 cm en todos ellos. Lo que
cambia entre modos es el radio cubierto:

| Modo | Radio | Grid | Frecuencia |
| --- | --- | --- | --- |
| `detail` | 1 m | 200×200 | ~12 Hz |
| `medium` | 2 m | 400×400 | ~12 Hz |
| `panorama` | 3 m | 600×600 | ~12 Hz |

El grid se publica como JSON en el tópico `lidar_grid`. Los puntos con más
de 0,35 s de antigüedad se descartan antes de construirlo.

### Modo paredes

Inmersivo y opcional (`walls_enabled`): alimenta la escena 3D del headset,
no los paneles 2D. El sistema acumula hasta 150 000 puntos en una ventana de
4 s y procesa el lote a ~1 Hz, en cinco etapas:

1. **Proyectar** los puntos a un grid 2D de 10 cm, con 0,5 m de margen.
2. **Morfología** para cerrar huecos y quitar ruido: dilatación (kernel 3,
   1 pasada), cierre (kernel 5, 2 pasadas) y apertura (kernel 2, 1 pasada).
3. **Componentes conectados**, descartando los de menos de 80 px de área.
4. **Simplificar** las polilíneas con épsilon de 4 px, descartando las de
   menos de 8 px de longitud.
5. **Fusionar** segmentos: se unen los que difieren menos de 15°, con ajuste
   a 3 px y extensión máxima de 4 px, y se alinean a la ortogonal con la
   misma tolerancia de 15°.

El orden importa. Cerrar antes de abrir une los tramos de una misma pared
que el LiDAR ve con huecos, y solo después se elimina el ruido suelto; al
revés, la apertura borraría puntos que el cierre necesitaba.

La salida son segmentos de pared compactos. Viajan en binario por el puerto
5007, con los identificadores `WSNP` para el snapshot completo y `WDEL` para
los deltas.

### Modo puntos

También inmersivo (`points_enabled`). Publica hasta 12 000 puntos crudos por
paquete a ~8 Hz, por el puerto 5007, con los identificadores `LPSN` y `LPFR`.

## RealSense D435i

### Video

La cámara entrega un stream RGB de 640×480 a un máximo de 30 fps,
comprimido en JPEG con calidad 85. Se publica en el tópico `video_rgb`, por
el puerto 5555.

La profundidad se corrige con una curva de calibración interpolada entre
160 mm y 1000 mm.

### Visión por computadora

Corre **en CPU**, no en GPU, y cada modo carga un modelo distinto. Los dos no
son de la misma familia, cosa fácil de pasar por alto al montar el entorno:

| Modo | Modelo | Salida |
| --- | --- | --- |
| `pose` | `yolov8n-pose.pt` | Keypoints de pose corporal |
| `segment` | `yolo26n-seg.pt` | Máscaras de segmentación |

<ParameterTable
  caption="Parámetros de inferencia"
  rows={[
    { parameter: 'Dispositivo', value: 'CPU', unit: '—', notes: 'La NUC no lleva GPU dedicada' },
    { parameter: 'Tamaño de entrada', value: '640', unit: 'px' },
    { parameter: 'Umbral de confianza', value: '0,70', unit: '—', notes: 'Detección descartada por debajo' },
    { parameter: 'Umbral por keypoint (pose)', value: '0,20', unit: '—' },
    { parameter: 'Máscara mínima (segmentación)', value: '200', unit: 'px', notes: 'Descarta manchas sueltas' },
    { parameter: 'Radio de muestreo de profundidad', value: '10', unit: 'px', notes: 'Promedia un disco, no un píxel suelto' },
    { parameter: 'Profundidad máxima válida', value: '2500', unit: 'mm' },
    { parameter: 'Frecuencia de publicación', value: '10', unit: 'Hz' },
  ]}
/>

La profundidad de una detección no se lee del píxel central sino de un disco
de 10 px alrededor: un solo píxel de la RealSense puede venir sin dato o con
ruido, y una lectura errónea ahí desplaza el objeto entero en la escena.

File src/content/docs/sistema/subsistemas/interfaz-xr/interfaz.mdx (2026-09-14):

---
title: "Interfaz y controles"
description: Paneles, drive teleop, control de manipulador y feedback multisensorial en el headset.
---

import { ReplicationLevel, ParameterTable } from '@project';

La aplicación corre en modo passthrough MR sobre el Meta Quest 3. Un canvas
world-space flotante agrupa tres paneles, y el operador interactúa con ellos
por *ray interaction* desde los controladores del headset.

<figure>
  Vista de la interfaz de teleoperación en realidad mixta sobre Meta Quest
  <figcaption>La interfaz tal como la ve el operador: paneles de estado y sensores superpuestos sobre el entorno real.</figcaption>
</figure>

| Panel | Posición | Función |
| --- | --- | --- |
| Izquierdo | Izq. | Estado de conexión, controles de cámara, parada de emergencia |
| Central | Centro | Stream de video principal y grid LiDAR 2D |
| Derecho | Der. | Sliders de manipulador y gripper, rotación de cámara |

La interfaz pide a la NUC solo los datos que está mostrando. Los streams que
nadie tiene abierto **no se transmiten**.

<ReplicationLevel
  level="described"
  provides={[
    'Disposición de los tres paneles y función de cada control',
    'Parámetros del teleoperado, los rangos articulares y el código de color del grid',
    'Modos de control, su exclusividad y qué arma cada uno',
    'Valores de feedback háptico y de audio',
  ]}
  missing={[
    'Las escenas y prefabs de Unity que materializan estos paneles',
    'Capturas o grabación de la interfaz en funcionamiento dentro del headset',
  ]}
/>

## Panel izquierdo

El `RobotStatusPanel` se refresca a ~5 Hz desde el tópico `stat`. Muestra el
estado de conexión, la IP de la NUC y la del headset, el modo activo, los
FPS y la resolución del video, y el estado de cada sensor.

**Parada de emergencia.** Un botón envía `stop_all` y `master_disarm` a la
vez. Detiene toda la locomoción y deja los motores en `DISARMED` de
inmediato.

**IP de la NUC.** Un teclado numérico virtual permite cambiar la IP sin
quitarse el headset. Hace falta porque la red del laboratorio no asigna IP
fija a la NUC, según se explica en [Puesta en
marcha](/operacion/#puesta-en-marcha). La aplicación guarda el
valor en `PlayerPrefs`, así que sobrevive entre sesiones.

## Panel central

<ParameterTable
  caption="Stream de video"
  rows={[
    { parameter: 'Resolución', value: '640×480', unit: 'px' },
    { parameter: 'Tasa de cuadros', value: '~30', unit: 'fps' },
    { parameter: 'Latencia objetivo', value: '< 150', unit: 'ms', notes: 'extremo a extremo, sin medir formalmente todavía' },
  ]}
/>

La resolución de 640×480 es un techo empírico, no una elección arbitraria.
Por encima de ese valor aparecen frames en blanco y caídas de FPS.

El grid LiDAR 2D usa un código de color fijo:

| Color | Significado |
| --- | --- |
| Blanco | Espacio libre |
| Negro | Obstáculo |
| Verde | Posición del robot |
| Azul | Frente del robot |

Los modos `detail`, `medium` y `panorama` usan el mismo radio y el mismo
tamaño de grid descritos en
[Percepción](/sistema/subsistemas/servidor-percepcion/percepcion/).

## Panel derecho — manipulador y gripper

El panel tiene cuatro sliders independientes:

| Control | Articulación | Rango |
| --- | --- | --- |
| Base | Rotación de la base | −80° a +80° |
| Codo | Articulación del codo | 0° a 136,5° |
| Muñeca | Orientación de la muñeca | −220° a 0° |
| Gripper | Apertura de la pinza | 0 mm a 80 mm |

Mientras el operador ajusta los sliders, un modelo 3D —el *ghost robot*—
muestra la pose que resultaría, antes de enviar nada al robot real.

Dos botones cierran la interacción. **Home** envía `manip_home`, que dispara
la rutina de homing en el CL57T. **Implement** envía la pose completa en un
solo mensaje.

## Drive teleop — joystick derecho

```text
joystick.y (±1) → v (avance/retroceso)
joystick.x (±1) → w (giro)

left  = clamp(v - w, -255, 255)
right = clamp(v + w, -255, 255)
```

<ParameterTable
  caption="Parámetros del teleoperado de base"
  rows={[
    { parameter: 'Frecuencia de envío', value: '15', unit: 'Hz' },
    { parameter: 'Zona muerta en Unity', value: '18', unit: '%', notes: 'Sobre el joystick crudo, antes de enviar' },
    { parameter: 'Ganancia de giro', value: '1,0', unit: '—' },
    { parameter: 'Velocidad máxima', value: '±255', unit: 'raw', notes: '≈ ±70 % de duty en hardware' },
    { parameter: 'Watchdog en la NUC', value: '350', unit: 'ms', notes: 'sin comando en ese plazo, se fuerza un stop' },
  ]}
/>

### Hay dos zonas muertas, no una

Es la clase de detalle que cuesta horas si se descubre depurando. El
joystick pasa por **dos** filtros de reposo, en dos máquinas distintas:

| Dónde | Valor | Sobre qué actúa |
| --- | --- | --- |
| Unity, antes de enviar | 0,18 | El eje crudo del joystick del Quest |
| NUC, al recibir `drive_cmd` | 0,08 | La velocidad normalizada ya mezclada |

Manda la de Unity, que es la más alta: un valor filtrado ahí nunca llega a
la NUC. La de la NUC es una segunda red de seguridad, y protege también
frente a un cliente distinto de esta aplicación. Cambiar solo una de las dos
produce un comportamiento que no cuadra con ninguna de ellas.
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

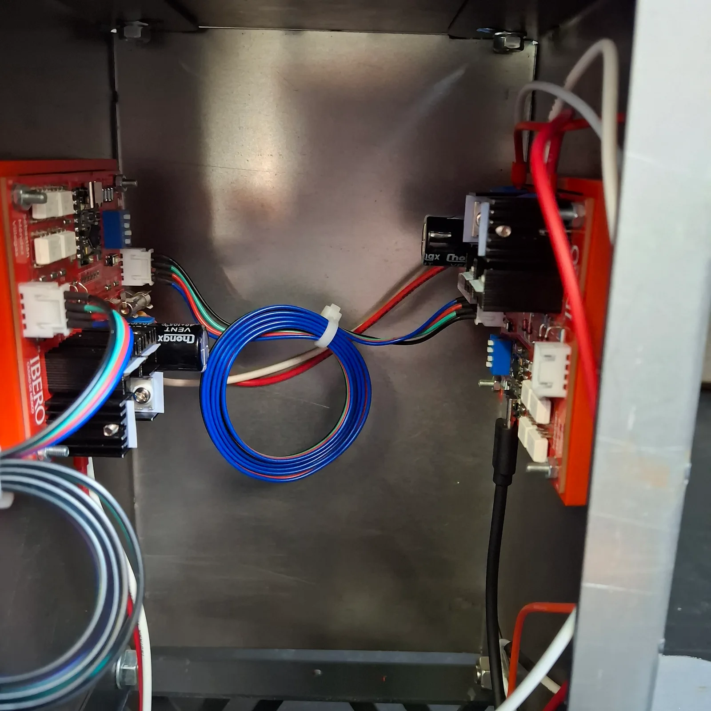
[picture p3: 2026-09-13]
public/images/build/caja-elevacion-interior-electronica.webp

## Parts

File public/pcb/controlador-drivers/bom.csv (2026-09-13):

Designator | Footprint | Quantity | Value | LCSC Part #
C1, C3 | 1206 | 2 | 100nF
CONN01X06 | JST_EH_B6B-EH-A_1x06_P2.50mm_Vertical | 1 | HC-05
D2 | 1206 | 1 | LED_D
D3 | 1206 | 1 | LED_P
DATA_IN1, DATA_OUT1 | JST_EH_B4B-EH-A_1x04_P2.50mm_Vertical | 2 | I2C
ESP32-C3 | MODULE_ESP32-C3_SUPERMINI | 1 | ESP32-C3_SUPERMINI_SMD
R1, R10, R11, R3, R4, R7, R9 | 1206 | 7 | 330
R16 | 1206 | 1 | 10k
R20, R21 | 1206 | 2 | 4.7k
R5 | 1206 | 1 | 3.3k
SW2 | SW_RS-032G05A3-SMRT | 1 | SW_Push
U1, U2, U3, U4, U5, U6 | DIP-4_W7.62mm_SMDSocket_SmallPads | 6 | PC817
VP_IN1, VP_IN2, VP_IN3, VP_IN4 | TerminalBlock_MaiXu_MX126-5.0-02P_1x02_P5.00mm | 4 | Conn_01x02

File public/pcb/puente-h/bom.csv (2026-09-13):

Designator | Footprint | Quantity | Value | LCSC Part #
C1, C3, C4 | 1206 | 3 | 100nF
C2 | CP_Radial_D16.0mm_P7.50mm | 1 | 2200uF 50V
CONN01X06 | JST_EH_B6B-EH-A_1x06_P2.50mm_Vertical | 1 | HC-05
D1 | 1206 | 1 | LED
D2 | 1206 | 1 | LED_D
D3 | 1206 | 1 | LED_P
D4, D5, D6, D7 | D_DO-41_SOD81_P10.16mm_Horizontal | 4 | 1N47xxA
DATA_IN1, DATA_OUT1 | JST_EH_B4B-EH-A_1x04_P2.50mm_Vertical | 2 | I2C
F1 | Fuseholder_Clip-5x20mm_Keystone_3512_Inline_P23.62x7.27mm_D1.02x1.57mm_Horizontal | 1 | Fuse
J1, J2, J3, J4 | SolderWire-0.5sqmm_1x01_D0.9mm_OD2.1mm | 4 | Conn_01x01_Pin
M1 | TerminalBlock_MaiXu_MX126-5.0-02P_1x02_P5.00mm | 1 | Motor_DC
Q1, Q2 | TO-220-3_Vertical | 2 | IRF9540N
Q3, Q4 | TO-220-3_Vertical | 2 | IRF540N
R1, R14, R15, R2, R3, R4 | 1206 | 6 | 330
R10, R11, R16, R17, R18, R19, R7, R8 | 1206 | 8 | 10k
R12, R13, R6, R9 | 1206 | 4 | 2.2k
R20, R21 | 1206 | 2 | 4.7k
R5 | 1206 | 1 | 3.3k
SW2 | SW_RS-032G05A3-SMRT | 1 | SW_Push
SW3 | SW_DIP_SPSTx04_Slide_6.7x11.72mm_W7.62mm_P2.54mm_LowProfile | 1 | Dip_Switch_04
U1 | MODULE_ESP32-C3_SUPERMINI | 1 | ESP32-C3_SUPERMINI_SMD
U2, U3, U4, U5 | DIP-6_W7.62mm | 4 | 4N25
VP_IN1, VP_OUT1 | TerminalBlock_MaiXu_MX126-5.0-02P_1x02_P5.00mm | 2 | Conn_01x02

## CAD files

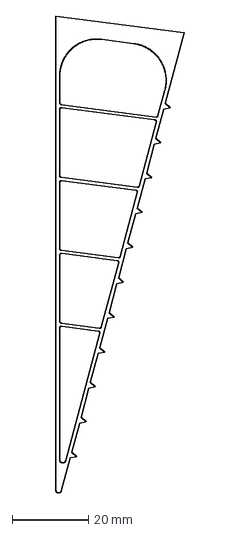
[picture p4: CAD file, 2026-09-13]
public/cad/dxf/gripper_flex.dxf
33.8 x 125.5 mm

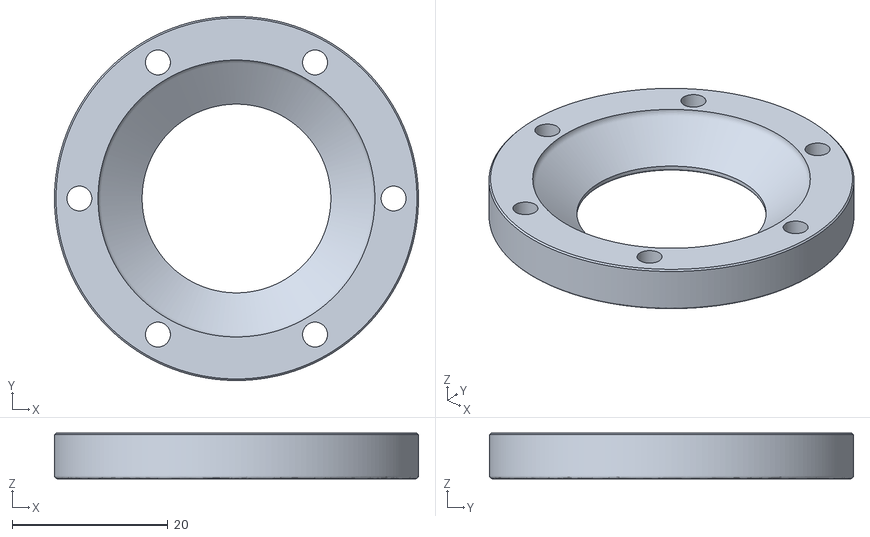
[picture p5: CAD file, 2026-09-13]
public/cad/mesh/bottom.obj
46.8 x 46.8 x 5.87

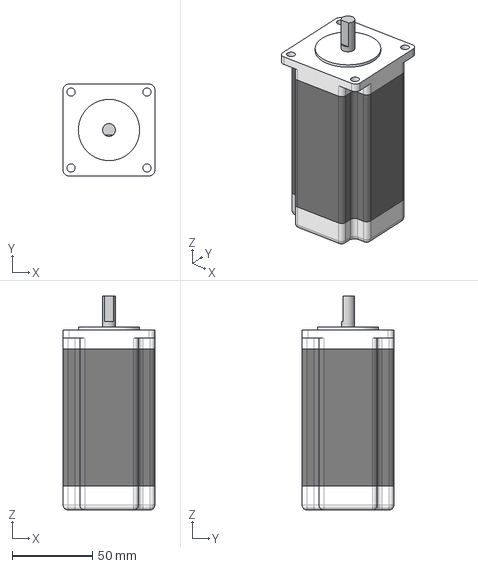
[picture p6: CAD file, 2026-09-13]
public/cad/reference/nema23.step
57.0 x 57.0 x 133.0 mm

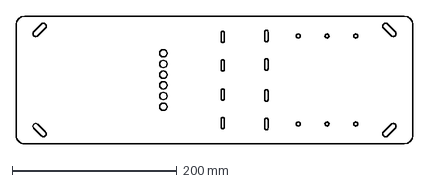
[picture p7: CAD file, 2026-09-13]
public/cad/dxf/soporte-drivers.dxf
481.7 x 155.0 mm

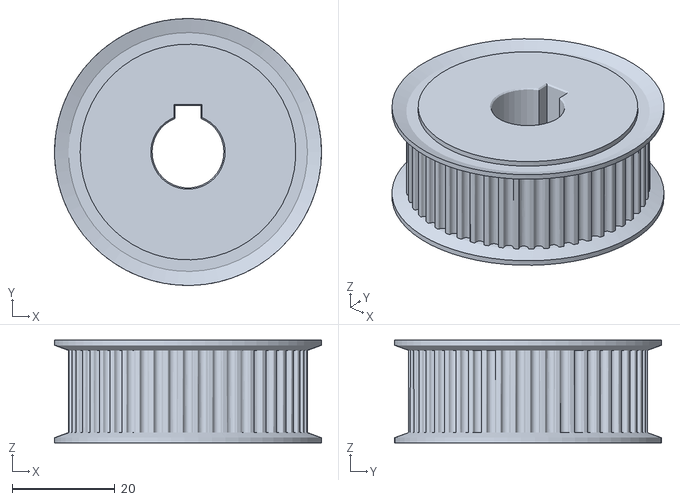
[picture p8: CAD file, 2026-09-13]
public/cad/mesh/T50.obj
52.0 x 52.0 x 20.0

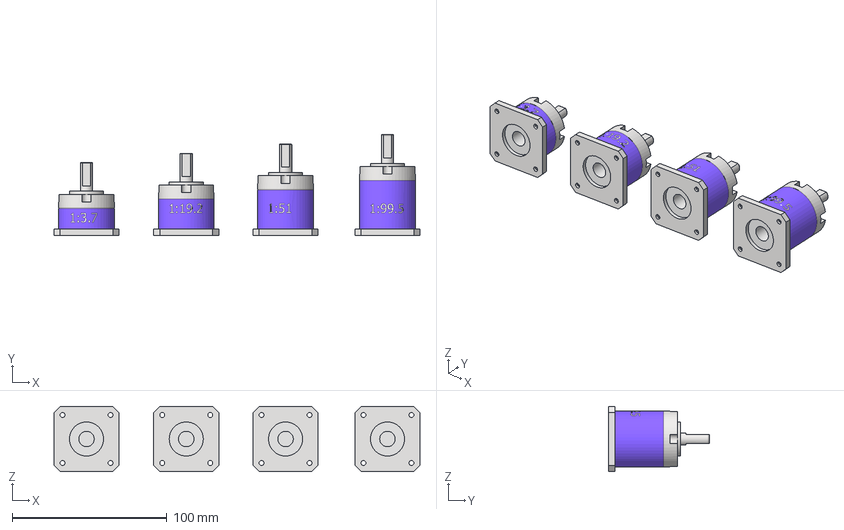
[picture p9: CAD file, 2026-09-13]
public/cad/reference/reductor_nema17.stp
236.3 x 65.0 x 42.0 mm
riduttore_nema17_1
riduttore_nema17_2
riduttore_nema17_3
riduttore_nema17_4

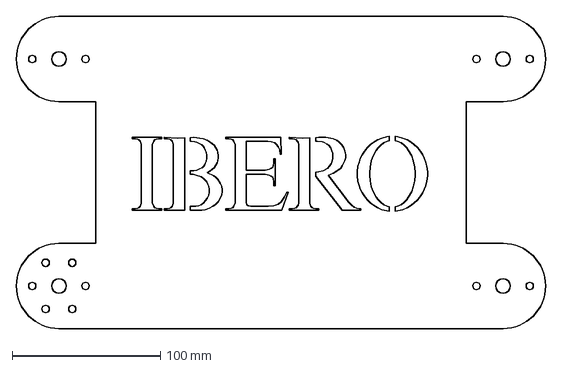
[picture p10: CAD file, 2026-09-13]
public/cad/dxf/primer-eslabon.dxf
357.6 x 210.8 mm

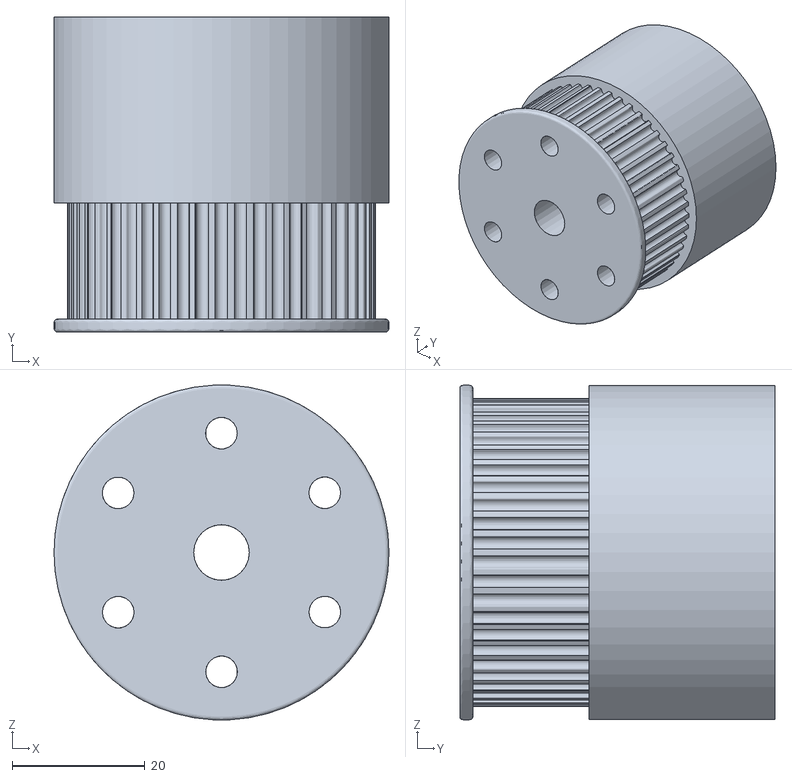
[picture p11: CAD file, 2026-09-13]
public/cad/mesh/htd3m_50T_Base.stl
50.5 x 47.6 x 50.5

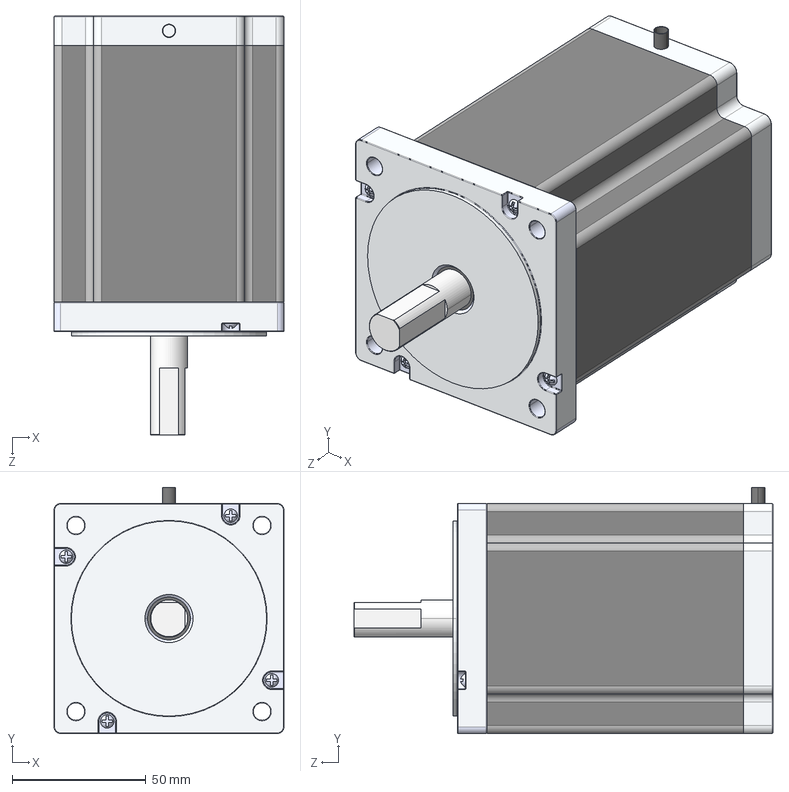
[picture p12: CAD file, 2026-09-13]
public/cad/reference/nema34.step
86.0 x 92.0 x 156.6 mm

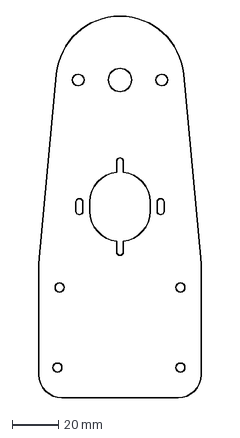
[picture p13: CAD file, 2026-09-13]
public/cad/dxf/soporte-nema17.dxf
70.0 x 164.5 mm

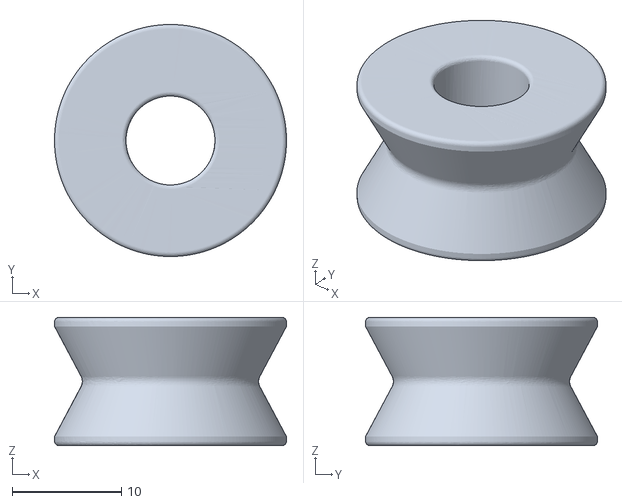
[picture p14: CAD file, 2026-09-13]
public/cad/mesh/inner.obj
21.2 x 21.2 x 11.7

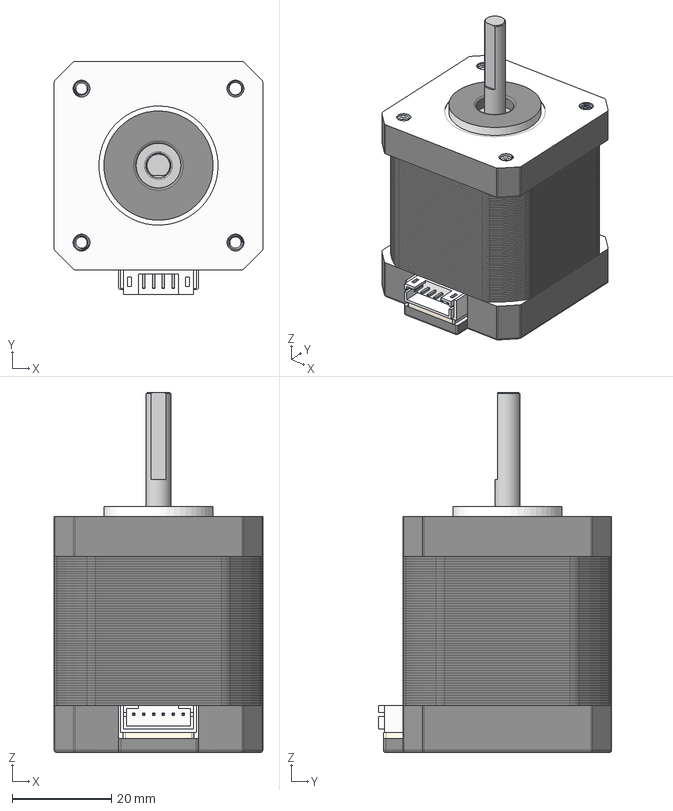
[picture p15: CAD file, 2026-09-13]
public/cad/reference/nema17.step
42.0 x 47.0 x 72.5 mm
Motor
Shaft

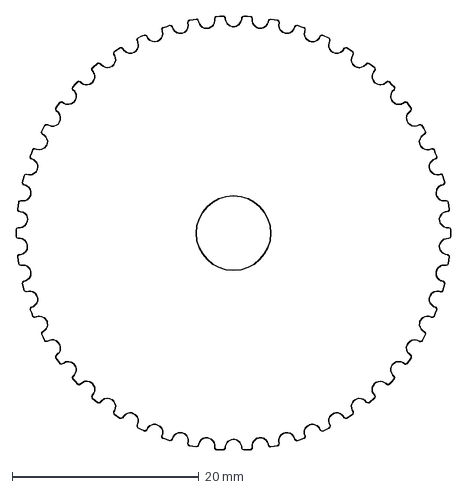
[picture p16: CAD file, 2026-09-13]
public/cad/dxf/silueta_50t.dxf
46.5 x 46.5 mm

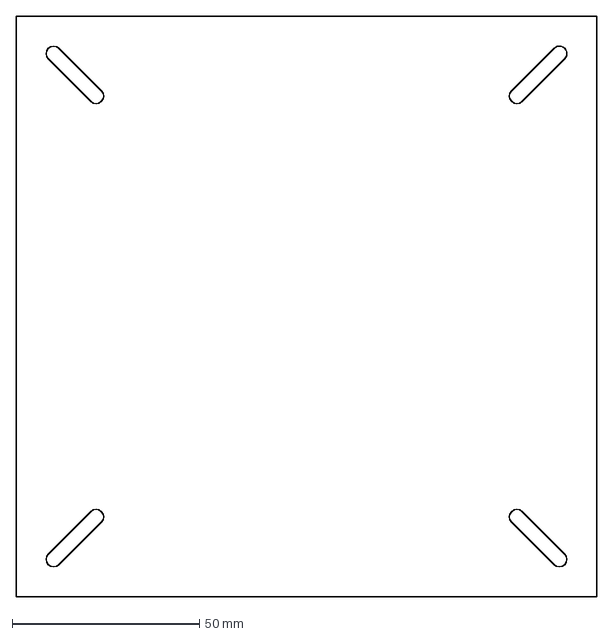
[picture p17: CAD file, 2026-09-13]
public/cad/dxf/balero-plano.dxf
155.0 x 155.0 mm

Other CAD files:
public/cad/dxf/soporte-top-rodamiento.dxf

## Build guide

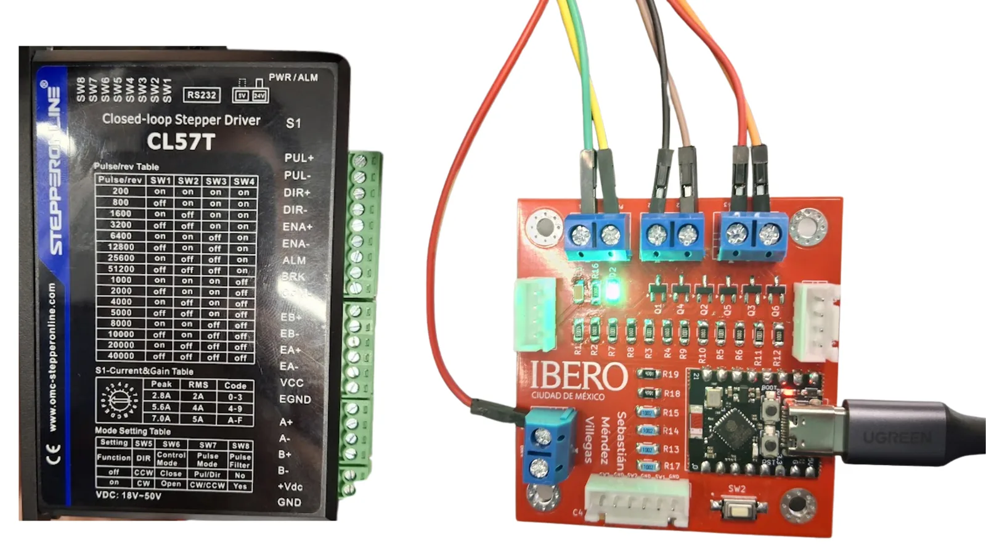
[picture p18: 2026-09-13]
public/images/build/controlador-cl57t-placa.webp

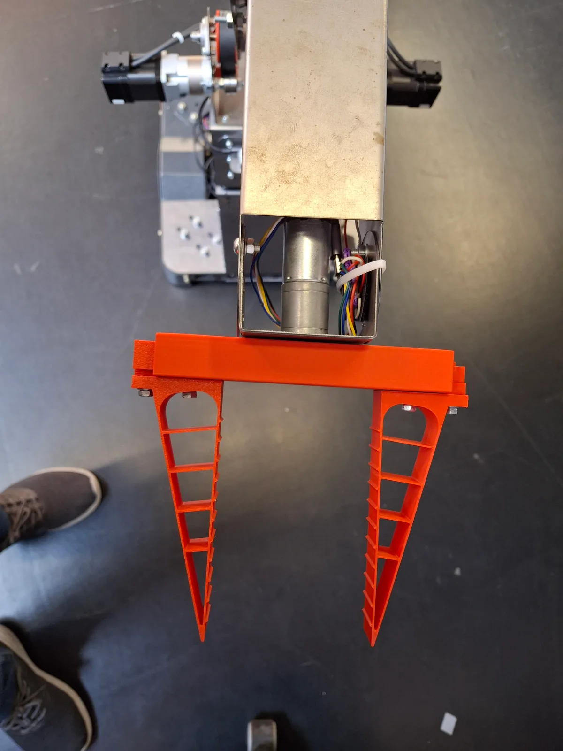
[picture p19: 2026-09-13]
public/images/build/gripper-vista-superior.webp

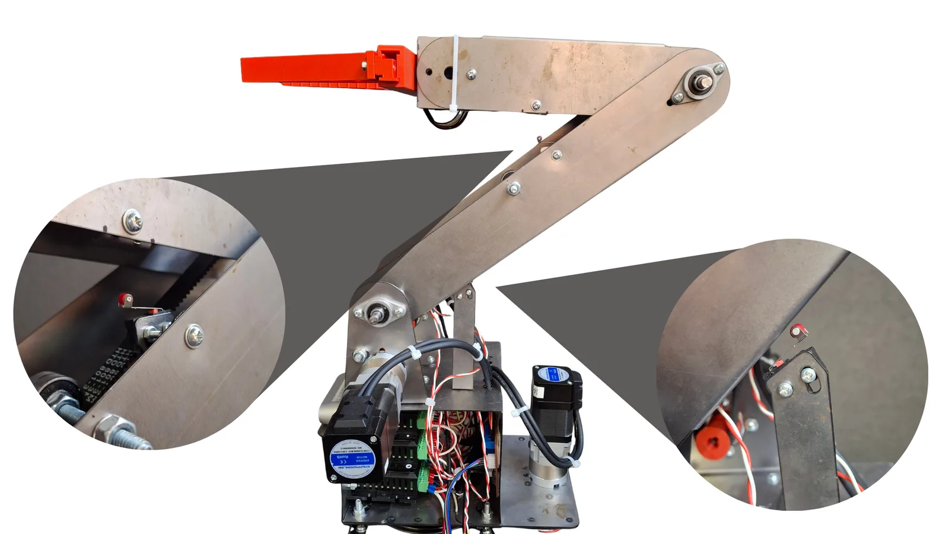
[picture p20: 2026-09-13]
public/images/build/finales-de-carrera.webp

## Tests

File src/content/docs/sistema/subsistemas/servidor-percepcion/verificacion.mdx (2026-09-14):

---
title: "Verificación — Servidor / percepción"
type: subsystem
subsystemId: SUB-SERVIDOR/VER
status: in-review
responsibility: Resultados de verificación de canales de datos y comunicación WiFi robot-NUC.
---

import { VerificationResult } from '@project';

La verificación de este subsistema comprueba dos cosas: que cada canal de
datos publica a la frecuencia esperada, y que el enlace WiFi entre el robot
y la NUC se mantiene estable durante una sesión de trabajo.

## Frecuencia por canal

<VerificationResult
  id="VER-SRV-001"
  requirement="El canal lidar_grid (RPLiDAR C1) publica entre 10 y 12 Hz"
  method="measurement"
  result="10–12 Hz medidos"
  status="pass"
/>

<VerificationResult
  id="VER-SRV-002"
  requirement="El canal video_rgb (RealSense D435i) publica a unos 30 fps"
  method="measurement"
  result="~30 fps medidos"
  status="pass"
/>

<VerificationResult
  id="VER-SRV-003"
  requirement="El tópico stat publica a unos 2 Hz"
  method="measurement"
  result="~2 Hz medidos"
  status="pass"
/>

## Lazo de comando

<VerificationResult
  id="VER-SRV-004"
  requirement="Un comando recibido en el puerto 5002 llega hasta el motor"
  method="test"
  result="Confirmado el canal de comando hasta el motor; el lazo completo no se verificó"
  status="pending"
/>

## Enlace WiFi

<VerificationResult
  id="VER-SRV-005"
  requirement="El enlace robot ↔ NUC se mantiene estable durante una sesión"
  method="demonstration"
  result="Sin desconexiones en una prueba de 10 minutos"
  status="pass"
/>

## Pruebas pendientes

Las siguientes pruebas quedaron documentadas en el proyecto original sin
ejecutarse:

| Prueba | Estado |
| --- | --- |
| Telemetría de encoders de tracción (10–20 Hz) | Pendiente de integración |
| Latencia de red local y extremo a extremo (XR → robot → XR) | Pendiente de medir |
| SLAM: generación de mapa en pasillo estructurado | Pendiente |
| Watchdog: el robot se detiene al perder conexión | Pendiente |
| Stream RGB-D completo al headset XR | Pendiente |

Conviene no confundir la segunda con el [experimento de latencia
WiFi](/latencia-wifi/#resultados) que
sí está ejecutado. Aquel mide el protocolo entre la interfaz MR y un nodo
edge simulado. La prueba pendiente mide el lazo físico completo, con el
robot real dentro.

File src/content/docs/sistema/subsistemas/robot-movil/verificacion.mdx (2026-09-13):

---
title: "Verificación — Robot"
type: subsystem
subsystemId: SUB-ROBOT/VER
status: validated
responsibility: Resultados de verificación de la plataforma móvil, el manipulador y sus controladores.
---

import { VerificationResult } from '@project';

Esta página reúne los resultados de verificación del subsistema, agrupados
por componente. Cada entrada registra el método empleado y el resultado
medido u observado, no solo un veredicto.

<figure>
  Prototipo del Puente H en protoboard durante una prueba de banco
  <figcaption>Prueba de banco del prototipo del Puente H, antes de fabricar la PCB.</figcaption>
</figure>

Los archivos de evidencia —los videos de cada prueba— todavía no se
migraron a este repositorio. Hasta que se copien, las entradas de abajo
citan el resultado registrado en la documentación original sin enlazar el
material. La [nota sobre la evidencia en video](#nota-sobre-la-evidencia-en-video)
al final de la página detalla qué falta.

## Puente H (tracción)

<VerificationResult
  id="VER-PH-001"
  requirement="Temperatura de los MOSFETs en el prototipo de protoboard"
  method="measurement"
  result="Máximo registrado: 61 °C bajo carga"
  status="pass"
/>

<VerificationResult
  id="VER-PH-002"
  requirement="Movimiento diferencial en superficie plana"
  method="demonstration"
  result="Estable"
  status="pass"
/>

<VerificationResult
  id="VER-PH-003"
  requirement="Respuesta a comandos de dirección (F/B/L/R)"
  method="demonstration"
  result="Correcta"
  status="pass"
/>

<VerificationResult
  id="VER-PH-004"
  requirement="Temperatura de MOSFETs bajo carga continua, 60 min"
  method="measurement"
  result="Dentro del rango — disipadores efectivos"
  status="pass"
/>

<VerificationResult
  id="VER-PH-005"
  requirement="Control remoto extremo a extremo desde XR"
  method="demonstration"
  result="Completo"
  status="pass"
/>

## Manipulador 3 GDL

<VerificationResult
  id="VER-MAN-001"
  requirement="Rangos de movimiento por articulación"
  method="test"
  result="Alcanzados"
  status="pass"
/>

<VerificationResult
  id="VER-MAN-002"
  requirement="Juego en transmisiones HTD3M"
  method="inspection"
  result="Sin juego excesivo"
  status="pass"
/>

<VerificationResult
  id="VER-MAN-003"
  requirement="Velocidad de movimiento rápido"
  method="demonstration"
  result="Funcional"
  status="pass"
/>

<VerificationResult
  id="VER-MAN-004"
  requirement="Control remoto integrado XR → NUC → manipulador"
  method="demonstration"
  result="Sin ejecutar en la última verificación registrada"
  status="pending"
/>

## CL57T (ejes del manipulador)

<VerificationResult
  id="VER-CL-001"
  requirement="Movimiento de articulaciones (estático)"
  method="test"
  result="Rangos alcanzados, sin pérdida de pasos detectada"
  status="pass"
/>

<VerificationResult
  id="VER-CL-002"
  requirement="Rutina de búsqueda de cero (homing)"
  method="demonstration"
  result="Funcional con finales de carrera"
  status="pass"
/>

<VerificationResult
  id="VER-CL-003"
  requirement="Control remoto desde interfaz XR"
  method="demonstration"
  result="Integración incompleta en la última verificación registrada"
  status="pending"
/>

## Gripper

<VerificationResult
  id="VER-GRIP-001"
  requirement="Movimiento absoluto de 0 mm a 80 mm (recorrido completo)"
  method="test"
  result="Sin pérdida de posición"
  status="pass"
/>

<VerificationResult
  id="VER-GRIP-002"
  requirement="Detección de stall contra obstáculo"
  method="test"
  result="Detiene el motor en 500 ms, sin daño al mecanismo"
  status="pass"
/>

<VerificationResult
  id="VER-GRIP-003"
  requirement="Persistencia de calibración tras reinicio"
  method="test"
  result="Calibración recuperada correctamente desde JSON"
  status="pass"
/>

<VerificationResult
  id="VER-GRIP-004"
  requirement="Control remoto desde la NUC (COM5)"
  method="measurement"
  result="Latencia menor a 50 ms"
  status="pass"
/>

## Nota sobre la evidencia en video

La documentación original conserva un video por prueba en `assets/vid/`.
Son ocho archivos, unos 77 MB en total:

| Archivo | Prueba que documenta |
| --- | --- |
| `Test_puenteH_web.mp4` | Salida del puente H en osciloscopio, en protoboard y en PCB final |
| `Test_movil_rehabilitacion_web.mp4` | Plataforma móvil en control manual |
| `Test_movil_web.mp4` | Plataforma móvil teleoperada |
| `Test_manipulador_basic_rutine_web.mp4` | Rutina básica del manipulador |
| `Test_calibracion_web.mp4` | Calibración de cero |
| `Test_load_web.mp4` | Manipulador bajo carga |
| `Test_repetitibilidad_web.mp4` | Repetibilidad del manipulador |
| `Test_gripper_web.mp4` | Gripper |

Ninguno se copió todavía a este repositorio. Mover 77 MB de video a un repo
Git es una decisión con consecuencias —Git LFS, hosting externo, o
aceptarlo tal cual— y sigue pendiente. Cuando se resuelva, cada archivo debe quedar
enlazado como `evidence` en su `VerificationResult` correspondiente.

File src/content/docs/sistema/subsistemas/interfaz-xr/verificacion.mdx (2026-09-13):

---
title: "Verificación — Visor Meta Quest"
type: subsystem
subsystemId: SUB-XR/VER
status: validated
responsibility: Resultados de verificación de la aplicación Unity y sus controles.
---

import { VerificationResult } from '@project';

Todas las verificaciones de este subsistema son demostraciones sobre el
headset real, no pruebas instrumentadas. Confirman que cada elemento de la
interfaz responde en operación; no miden desempeño.

## Visualización

<VerificationResult
  id="VER-XR-001"
  requirement="El canvas world-space se muestra correctamente sobre el passthrough MR"
  method="demonstration"
  result="Funcional en el headset"
  status="pass"
/>

<VerificationResult
  id="VER-XR-002"
  requirement="El VideoPanel muestra el stream RGB del robot en tiempo real"
  method="demonstration"
  result="Verificado"
  status="pass"
/>

<VerificationResult
  id="VER-XR-003"
  requirement="El panel LiDAR 2D dibuja el grid de ocupación y permite cambiar de modo"
  method="demonstration"
  result="Verificado en los tres modos"
  status="pass"
/>

<VerificationResult
  id="VER-XR-004"
  requirement="El StatusPanel refleja conexión, estado de sensores y telemetría"
  method="demonstration"
  result="Verificado"
  status="pass"
/>

<VerificationResult
  id="VER-XR-007"
  requirement="La escena 3D dibuja las paredes y la nube de puntos del LiDAR"
  method="demonstration"
  result="Funcional"
  status="pass"
/>

## Control

<VerificationResult
  id="VER-XR-005"
  requirement="El joystick del headset conduce la base móvil (drive teleop)"
  method="demonstration"
  result="Funcional"
  status="pass"
/>

<VerificationResult
  id="VER-XR-006"
  requirement="Los sliders y el ghost robot comandan el manipulador 3 GDL y el gripper"
  method="demonstration"
  result="Funcional"
  status="pass"
/>

## Pendiente

<VerificationResult
  id="VER-XR-008"
  requirement="Gemelo digital URDF del robot dentro de la escena XR"
  method="demonstration"
  result="Sin implementar — planificado a mediano plazo"
  status="pending"
/>

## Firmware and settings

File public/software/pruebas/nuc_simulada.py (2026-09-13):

"""
NUC simulada para probar la aplicación del Meta Quest 3 sin el robot.

Corre en una PC de la misma red WiFi que el visor y abre los mismos puertos
que el coordinador de la NUC. Publica en el puerto 5555 un video de prueba
(tópico "video_rgb", JPEG 640 x 480) y muestra en consola cada comando que
el visor envía por el puerto 5002 (tópico "cmd", JSON). Si en el visor se ve
el video y aquí aparecen los comandos al mover los controles, la app y la red
funcionan.

En el visor, escribe la IP de esta PC como IP de la NUC.

Uso:
    pip install pyzmq numpy opencv-python
    python nuc_simulada.py
    python nuc_simulada.py --fps 15

Ctrl+C para salir.
"""

import argparse
import json
import socket
import sys
import time

import cv2
import numpy as np
import zmq

PUERTO_VIDEO = 5555
PUERTO_CMD = 5002
ANCHO, ALTO = 640, 480


def ip_local():
    s = socket.socket(socket.AF_INET, socket.SOCK_DGRAM)
    try:
        s.connect(("8.8.8.8", 80))
        return s.getsockname()[0]
    except OSError:
        return "127.0.0.1"
    finally:
        s.close()


def cuadro_de_prueba(n, fps_real):
    """Barras de color que se desplazan, con la hora y el contador de cuadros."""
    x = (np.arange(ANCHO) + n * 4) % ANCHO
    barras = np.zeros((ALTO, ANCHO, 3), dtype=np.uint8)
    barras[:, :, 0] = (x * 255 // ANCHO)[None, :]
    barras[:, :, 1] = 128
    barras[:, :, 2] = 255 - barras[:, :, 0]
    texto = "NUC simulada  #{}  {:.1f} fps  {}".format(n, fps_real, time.strftime("%H:%M:%S"))
    cv2.putText(barras, texto, (16, ALTO // 2), cv2.FONT_HERSHEY_SIMPLEX, 0.7, (255, 255, 255), 2)
    ok, jpeg = cv2.imencode(".jpg", barras, [cv2.IMWRITE_JPEG_QUALITY, 85])
    return jpeg.tobytes()


def main():
    parser = argparse.ArgumentParser(description=__doc__, formatter_class=argparse.RawDescriptionHelpFormatter)
    parser.add_argument("--fps", type=float, default=30.0)
    args = parser.parse_args()

    ctx = zmq.Context()
    video = ctx.socket(zmq.PUB)
    video.setsockopt(zmq.SNDHWM, 2)  # igual que la NUC: descartar antes que acumular
    video.bind("tcp://*:{}".format(PUERTO_VIDEO))

    comandos = ctx.socket(zmq.SUB)
    comandos.bind("tcp://*:{}".format(PUERTO_CMD))
    comandos.setsockopt(zmq.SUBSCRIBE, b"")

    print("IP de esta PC : {}".format(ip_local()))
    print("Video PUB     : tcp://*:{} (tópico video_rgb)".format(PUERTO_VIDEO))
    print("Comandos SUB  : tcp://*:{} (tópico cmd)\n".format(PUERTO_CMD))

    periodo = 1.0 / args.fps
    n, fps_real, t_fps, cuenta = 0, 0.0, time.time(), 0
    try:
        while True:
            t0 = time.time()
            video.send_multipart([b"video_rgb", cuadro_de_prueba(n, fps_real)])
            n += 1
            cuenta += 1
            if t0 - t_fps >= 1.0:
                fps_real, t_fps, cuenta = cuenta / (t0 - t_fps), t0, 0

            while True:
                try:
                    partes = comandos.recv_multipart(flags=zmq.NOBLOCK)
                except zmq.Again:
                    break
                if len(partes) >= 2:
                    crudo = partes[1].decode("utf-8", errors="ignore")
                    try:
                        crudo = json.dumps(json.loads(crudo), ensure_ascii=False)
                    except ValueError:
                        pass
                    print("[{}] {} {}".format(time.strftime("%H:%M:%S"), partes[0].decode(errors="ignore"), crudo))

            time.sleep(max(0.0, periodo - (time.time() - t0)))
    except KeyboardInterrupt:
        print("\nDetenido.")
    finally:
        video.close(linger=0)
        comandos.close(linger=0)
        ctx.term()
    return 0


if __name__ == "__main__":
    sys.exit(main())

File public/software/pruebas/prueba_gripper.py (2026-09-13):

"""
Prueba del controlador del gripper conectado directo a una PC por USB-C.

Hace lo mismo que la NUC por COM5: pide el estado con "p" y manda
posiciones con "m <mm>". Sin opciones solo lee el estado. Con --mover, si el
gripper está calibrado, lo lleva a cada posición de --posiciones y espera a
que termine (busy=0). Con --consola puedes escribir cualquier comando a mano.

Uso:
    pip install pyserial
    python prueba_gripper.py --puerto COM5
    python prueba_gripper.py --puerto COM5 --mover --posiciones 60 20 40
    python prueba_gripper.py --puerto COM5 --consola
"""

import argparse
import re
import sys
import time

import serial

BAUDIOS = 115200
PATRON = re.compile(r"GRIPPER_STATE\s+mm=(?P<mm>-?[\d.]+).*busy=(?P<busy>[01])\s+calibrated=(?P<cal>[01])")


def leer_estado(ser, plazo_s=1.0):
    """Pide el estado y devuelve (mm, busy, calibrado) de la última línea GRIPPER_STATE."""
    ser.write(b"p\n")
    limite = time.time() + plazo_s
    estado = None
    while time.time() < limite:
        linea = ser.readline().decode("utf-8", errors="ignore").strip()
        m = PATRON.search(linea)
        if m:
            estado = (float(m.group("mm")), m.group("busy") == "1", m.group("cal") == "1")
            break
        elif linea:
            print("  <", linea)
    return estado


def main():
    parser = argparse.ArgumentParser(description=__doc__, formatter_class=argparse.RawDescriptionHelpFormatter)
    parser.add_argument("--puerto", required=True)
    parser.add_argument("--mover", action="store_true")
    parser.add_argument("--posiciones", type=float, nargs="+", default=[60.0, 20.0, 40.0], help="mm, de 0 a 80")
    parser.add_argument("--consola", action="store_true", help="escribir comandos a mano")
    args = parser.parse_args()

    ser = serial.Serial(args.puerto, BAUDIOS, timeout=0.1)
    time.sleep(1.0)
    ser.reset_input_buffer()

    try:
        estado = leer_estado(ser)
        if estado is None:
            print("No llegó GRIPPER_STATE. ¿Es el puerto correcto y el firmware está corriendo?")
            return 1
        mm, busy, calibrado = estado
        print("Estado : {:.1f} mm · busy={} · calibrado={}".format(mm, int(busy), int(calibrado)))

        if args.mover:
            if not calibrado:
                print("Sin calibrar: los comandos de posición están bloqueados. Calibra con 'so' y 'sc'.")
                return 1
            for objetivo in args.posiciones:
                objetivo = max(0.0, min(80.0, objetivo))
                print("  > m {:.1f}".format(objetivo))
                ser.write("m {:.1f}\n".format(objetivo).encode("utf-8"))
                t0 = time.time()
                time.sleep(0.3)
                while True:
                    estado = leer_estado(ser)
                    if estado and not estado[1]:
                        print("    llegó a {:.1f} mm en {:.2f} s".format(estado[0], time.time() - t0))
                        break
                    if time.time() - t0 > 10:
                        print("    no terminó en 10 s (¿stall?)")
                        break
                    time.sleep(0.25)

        if args.consola:
            print("Consola: escribe comandos (? para la lista), vacío para salir.")
            while True:
                linea = input()
                if not linea.strip():
                    break
                ser.write((linea.strip() + "\n").encode("utf-8"))
                time.sleep(0.3)
                while ser.in_waiting:
                    print("  <", ser.readline().decode("utf-8", errors="ignore").strip())
    except KeyboardInterrupt:
        pass
    finally:
        ser.write(b"s\n")
        ser.close()
    return 0


if __name__ == "__main__":
    sys.exit(main())

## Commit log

2026-09-13 Documentación de Remote Hands en Astro + Starlight
    Sitio de documentación de ingeniería del robot móvil manipulador
    teleoperado: arquitectura, subsistemas, verificación, decisiones y
    artefactos de replicación (firmware, PCB, CAD, dataset de latencia).
    Incluye navegación por vista explosionada renderizada desde el CAD,
    alternable con el temario de lista desde el botón UI/UX.
    [T50.obj, balero-plano.dxf, bom.csv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]
2026-09-13 Desplegar en remote-hands.sebs.mx con GitHub Pages
    - site y base apuntan al subdominio; el sitio vive en la raíz.
    - El contenido escribe rutas desde la raíz y rehype-base las ajusta al
    base al compilar: mover el sitio de ruta solo cambia BASE.
    - SystemMap aplica BASE_URL a sus enlaces, igual que Artifact.
    - Workflow de despliegue en GitHub Pages, con Chromium para Mermaid.
    - Favicon SEBS: Starlight pedía un /favicon.svg inexistente.
2026-09-13 Fijar three en 0.183 para el build en CI
    @google/model-viewer 4.3.1 exige three@^0.183 como peer. Con three 0.186
    el npm 11 local instalaba igual, pero el npm 10 del runner (Node 22)
    abortaba con ERESOLVE. El pipeline de render funciona igual con 0.183.
2026-09-13 Vista explosionada: embebidos, globos con línea guía y pestañas en árbol
    - Robot se abre en plataforma móvil, manipulador (con la caja de
    elevación) y embebidos.
    - Escena nueva de embebidos: 2 Puente H, controlador de steppers y
    DRV8833 (marcador del controlador del gripper).
    - La NUC muestra el conjunto I²C y el controlador del gripper, que se
    conectan a ella.
    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
2026-09-13 Vista explosionada por rutas, Sensores y Conjunto I²C, página del CL57T rehecha
    - Panel sin listado de piezas: al señalar una pieza, el rótulo al pie del
    lienzo dice qué es; migas con «/» y documentos como etiquetas.
    - Un nodo se alcanza por varias rutas y el panel conserva la ruta por la
    que se llegó (p. ej. el CL57T por Robot/Embebidos o por NUC/Conjunto I²C).
    - Robot se abre en plataforma, manipulador, embebidos y sensores.
    - Escenas nuevas: Sensores (LiDAR, RealSense, 3 finales de carrera) y
    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
2026-09-13 Puente H con formato Sinopsis/PCB/Firmware, diagrama de conexiones estándar y renders frontales
2026-09-13 Diagrama de conexiones: codo en el cambio de fila
2026-09-13 Formato Sinopsis por bloques en el resto de páginas del panel, diagrama en estrella y nuevos renders
2026-09-13 Páginas del RPLiDAR C1 y la RealSense D435i, scripts de prueba desde PC y manipulador por conjuntos
2026-09-13 Ignorar cachés de Python
2026-09-13 Quitar páginas reservadas; páginas de Estructura y Mecanismo; gripper sin zoom; drivers y motores en el CL57T
2026-09-14 Reporte y Operar en cinco páginas con secciones, panel sin pestañas y redirecciones de las URLs anteriores
2026-09-14 Flechas de un solo trazo en los diagramas, estrella con entradas y salidas, finales de carrera en el CL57T, portada Quest-NUC-Robot y Puente H como un solo conjunto
2026-09-14 Artefactos en cuadrícula de tres columnas e icono de archivo relleno
2026-09-14 Conmutador con rótulo Modo y cabecera estable con el temario contraído
2026-09-14 Diagrama de arquitectura detallado en Comunicaciones
